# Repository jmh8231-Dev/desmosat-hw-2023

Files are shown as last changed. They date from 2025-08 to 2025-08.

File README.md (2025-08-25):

# DesmoSAT – 모듈형 캔위성 하드웨어 (2023)

> 모듈화를 통해 **저비용·고유연성**을 달성한 소형 위성 하드웨어 플랫폼  
> 공통 코어 + 교체식 임무 보드 + 착륙 보드 = 빠른 재사용/응용

<!-- 히어로: 실물 사진 준비 전, 회로도 콜라주로 임시 노출 -->
<!-- 실물 사진을 올리면 아래 경로로 교체: docs/images/hero-boards.png -->
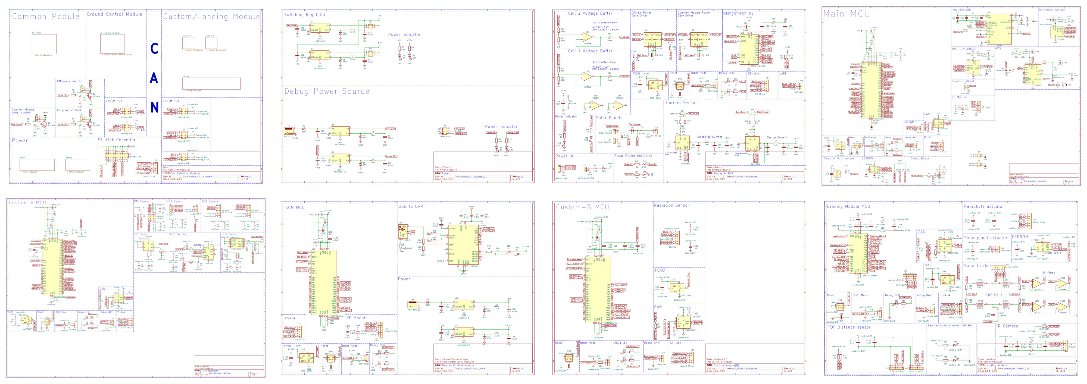
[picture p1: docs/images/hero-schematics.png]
DesmoSAT Boards


## 개요
DesmoSAT은 **모듈 교체만으로 임무를 바꿀 수 있게 설계된 캔위성(CanSat) 하드웨어 플랫폼**입니다.  
공통 코어(Common)와 전력/배터리 관리(BMS), 임무 모듈(Custom A/B), 착륙 모듈(Landing)을 단일 **CAN 2.0B** 버스로 연결하고, **전원·통신·ST-Link가 표준화된 인터페이스**로 제공되어 보드를 ‘플러그인’처럼 교체하면 즉시 재사용이 가능합니다.  
이 구조는 설계 변경 범위를 최소화해 **개발 기간을 단축**하고 **반복 제작 비용을 절감**하며, 현장 운용 중에도 유지보수와 확장을 쉽게 합니다.  
데모 임무로는 **화산 위험 징후 탐지**(가스/분진, IR/VL, ToF 기반)를 구현했습니다.

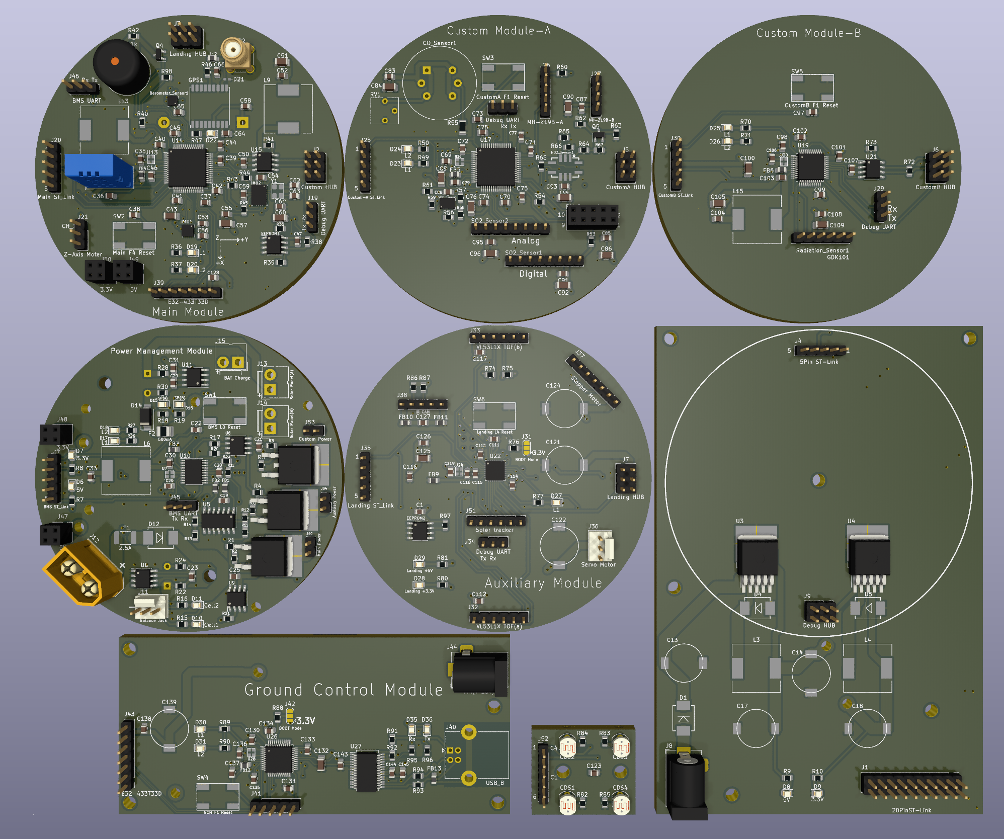
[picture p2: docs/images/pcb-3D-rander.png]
DesmoSAT PCB


## 핵심 포인트
- **모듈 스왑 기반 임무 전환**: 공통 코어는 유지, 임무 보드만 교체 → 빠른 재활용/확장  
- **표준화된 인터페이스**: 전원·CAN·ST-Link 핀아웃 통일 → 설계/디버그 일관성 확보  
- **개발/운용 효율**: 변경 영향 범위 축소 → 개발 기간 단축, 반복 제작·정비 비용 절감  
- **데모 임무**: 화산 위험 징후 탐지(가스/분진 + IR/VL + ToF), 군사 동향 정찰 위성(방사능 센서 + IR/VL + ToF)

> 설계/출력 도구: **KiCad 8/9** 

---

## 모듈 구조

| 모듈 | 목적(키워드) | 핵심 부품(키워드) |
|---|---|---|
| **Common** | 비행 컴퓨터/통신/센서 허브 | STM32F4, CAN(SN65HVD231), RF(433 MHz 1 W), GPS(MAX-M10S), IMU(BNO085/ICM-20602), Baro(LPS22HB), EEPROM |
| **Battery & BMS** | 전원/충전/안전 관리 | STM32L0, LM2596S 5 V/3.3 V, INA219B(전류), LM324A(셀버퍼), TC427(파워 게이팅), Solar 입력 |
| **Custom A** | 화산 임무용 가스/분진 센싱 | STM32F4, SO₂/CO/CO₂/CH₄/TVOC/PM 센서, CAN, TCXO |
| **Custom B** | 방사선 임무(확장) | STM32F1, GDK101(방사선), CAN, TCXO |
| **Landing** | 낙하/착지/추적 | STM32L4, VL53L1X(ToF), IR/VL 카메라 I/F, CDS 트래커, 서보/스테퍼, CAN |
| **Ground Control** | 지상국 수신/표시 | STM32F1, RF(E32-433T30D), FT232RL(USB-UART) |

<!-- 블록 다이어그램(상위 시트) 스크린샷 -->
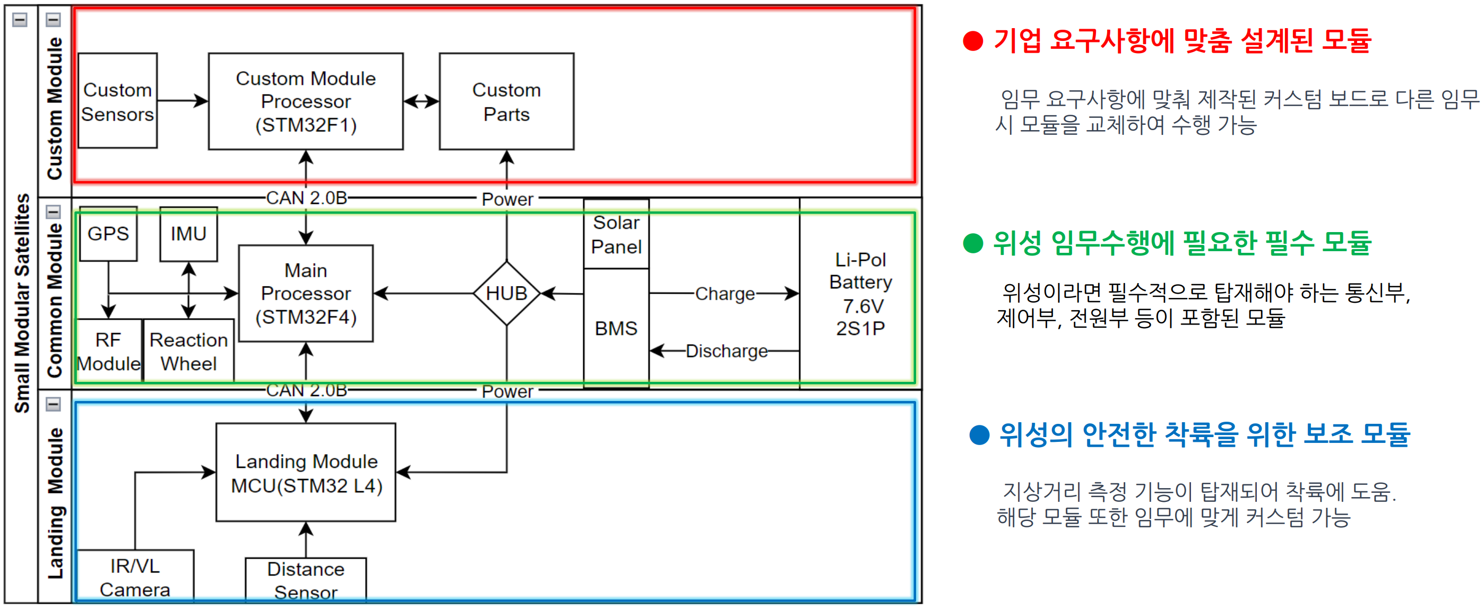
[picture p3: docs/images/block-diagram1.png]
Block Diagram

---

## 데모 임무 A: 화산 위험 징후 탐지
  활화산의 불안 징후를 감지하여 해당 화산의 폭발이 임박했는지 데이터를 지속
해서 Logging 하여 화산이 폭발하기 전 지역 주민이 대피할 수 있도록 하는 위성
이다.
  해당 캔 위성에는 화산에서 분출되는 다양한 가스의 농도를 측정해주는 모듈이
장착되어 화산 상공에서 낙하하며 각 가스의 농도를 측정한다. 그 후 착륙 모듈에
장착된 VL, IR 카메라를 사용하여 화산 상공의 모습과 화산지역의 온도를 측정한
다. 그 후 비교적 온도가 낮은 지역으로 낙하산 줄을 조정하여 착륙을 유도하고 착
륙한 뒤에는 메인 모듈에 내장된 IMU를 사용하여 화산지역의 지진파를 지속해서
측정한다.
  마지막으로 각 모듈에서 수집된 데이터를 기반으로 메인 컴퓨터가 화산 분화 가
능성을 대략 연산한 뒤 각 센서 수치와 함께 안전한 곳에 있는 지상국으로 데이터
를 보내주어 지질학자가 해당 데이터를 정밀 분석하여 해당 화산의 분화 가능성을
최종적으로 산출할 수 있다.

- **Custom A**: 하강 중 **SO₂/CO/CO₂/CH₄/TVOC/PM** 연속 측정 → 패킷 전송  
- **Landing**: **IR/VL 이미지**로 열점/지형 파악, **ToF**로 지면 거리 → **낙하산 라인 제어**(더 안전/저온 지역으로 착지 유도)  
- **Common**: 착지 후 **IMU 기반 미소진동(지진파) 모니터링**, RF 링크로 지상국에 로그 전송  
- **지상국**: 실시간 그래프/지도화, **베이스라인 대비 변화량** 분석

<!-- Custom A: 실물 사진 준비 전, 회로도 이미지 임시 노출 -->
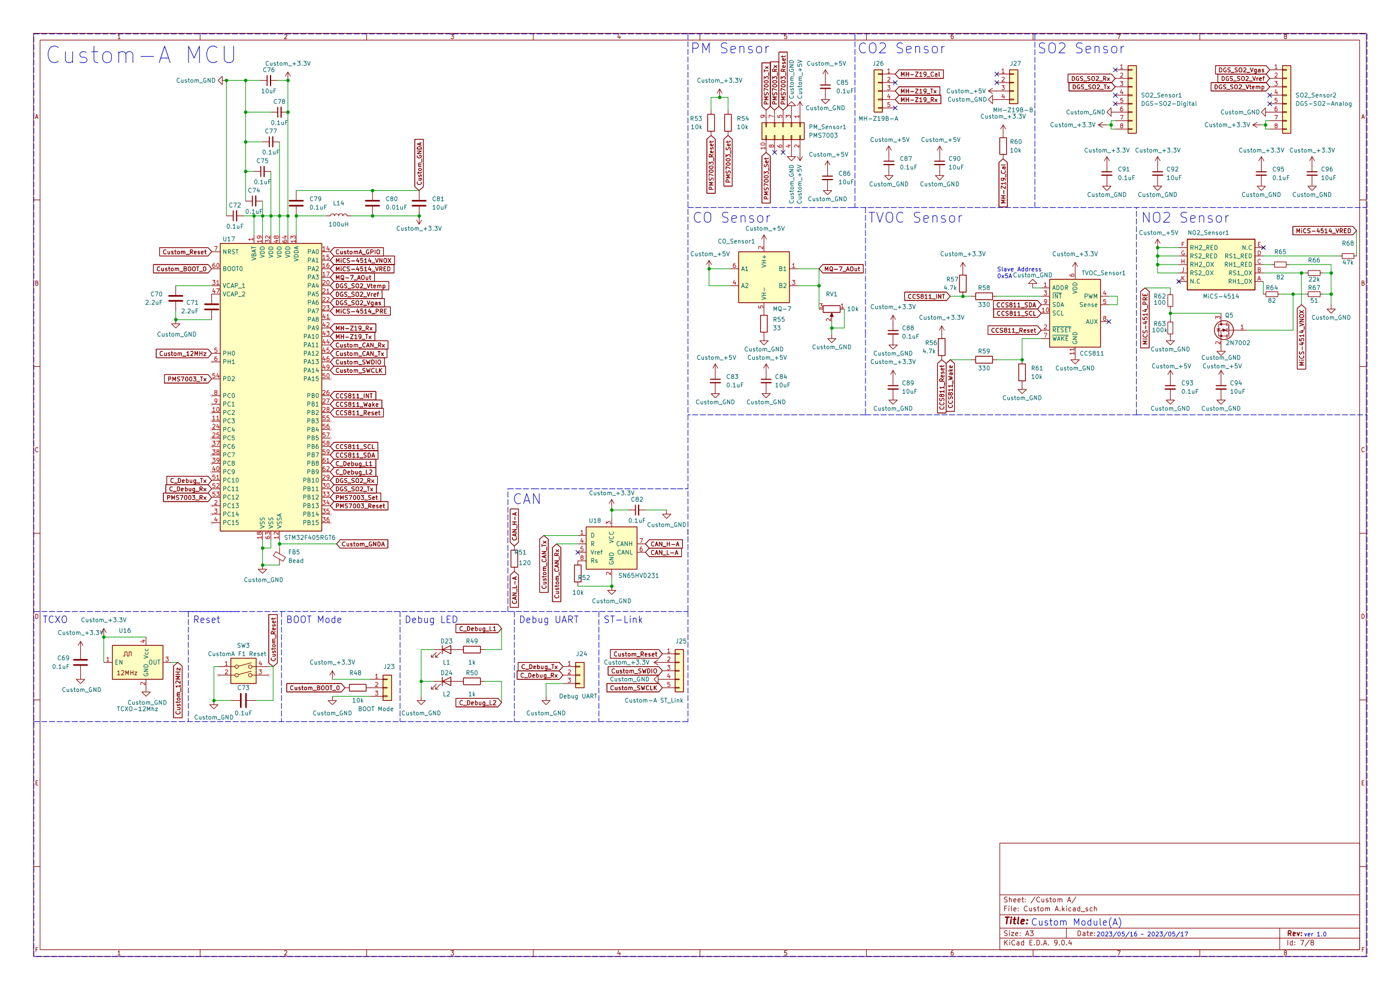
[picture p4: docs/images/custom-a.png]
Custom A – Gas/PM Payload


## 데모 임무 B: 군사 동향 정찰 위성
  적국의 핵실험 유무 및 국사적 움직임을 관측하기 위해 최상단 모듈을 방사능
측정 센서와 풍향 풍속 센서가 장착된 모듈로 교체한 뒤 캔 위성을 발사하여 핵실
험 유력 장소 상공 방사능 농도를 측정한다. 동시에 착륙 모듈에 장착된 IR/VL 카
메라를 사용하여 지표의 온도, 이미지를 보고 핵실험 유무를 판단할 수 있다.
  착륙한 뒤에는 화산 위험 징후 감지 위성과 동일하게 메인 모듈에 내장된 IMU
를 사용하여 지진파를 지속해서 감지하기 때문에 추가적인 핵실험 여부도 판단할
수 있는 위성이다. 
  또한 같은 위성을 원전 사고 현장에 발사한다면 방사성 물질의
피해 범위를 산출할 수도 있다

- **Custom B**: 하강 중 **방사능 농도** 연속 측정 → 패킷 전송  
- **Landing**: **IR/VL 이미지**로 열점/지형 파악, **ToF**로 지면 거리 → **낙하산 라인 제어**(목표 지역으로 유도 및 핵실험 유무 판단)  
- **Common**: 착지 후 **IMU 기반 미소진동(지진파) 모니터링**, RF 링크로 지상국에 로그 전송(추가 핵실험 판단)
- **지상국**: 실시간 그래프/지도화, **베이스라인 대비 변화량** 분석

<!-- Custom B: 실물 사진 준비 전, 회로도 이미지 임시 노출 -->
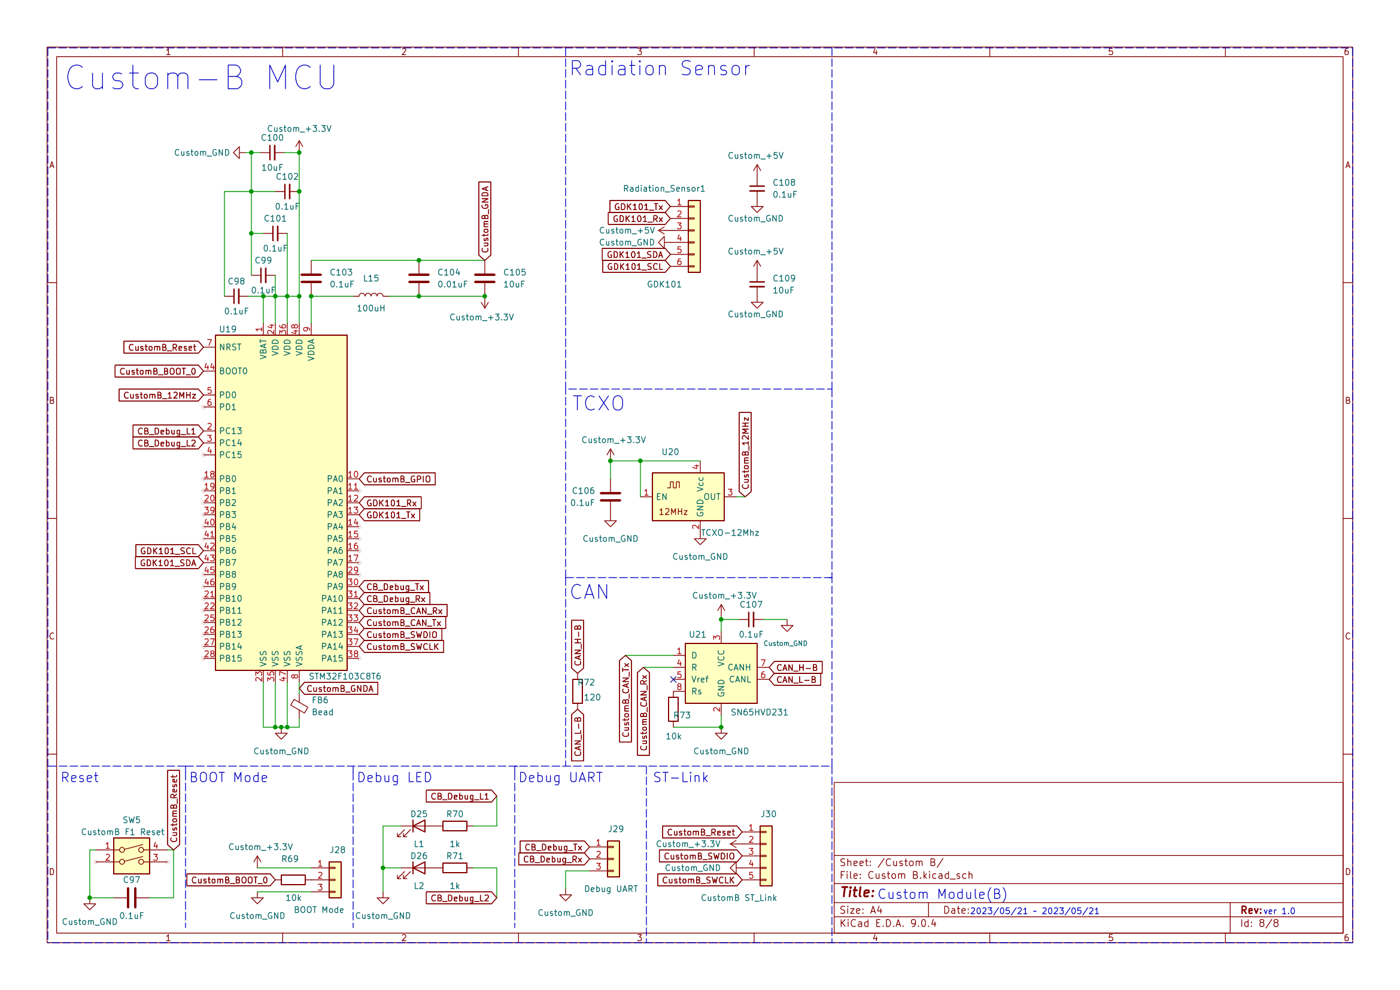
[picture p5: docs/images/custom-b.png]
Custom B – Gas/PM Payload


---

## 시스템 개요

### 통신/제어
- **CAN 2.0B**: 모듈 간 명령·텔레메트리 버스
- **RF 433 MHz 1 W**: 지상국 링크(센서/상태/좌표)
- **ST-Link**: 전 모듈 SWD 디버그/펌웨어 업데이트

### 전원/충전
- **Li-Po 2셀 + BMS**: 저전압 보호/전류 모니터/모듈 파워게이팅
- **스위칭 레귤레이터**: LM2596S-5/-3.3 (효율), 디버그 전원 레일 분리
- **Solar 충전**: 배터리 레벨에 따라 모듈 **절전/복귀** 제어

### 센서/액추에이터
- **가스/분진**: SO₂, CO, CO₂, CH₄, TVOC, PM
- **IMU**: BNO085(9축), ICM-20602(6축)
- **GPS**: MAX-M10S
- **CDS Solar Tracker**: 4-셀 + LM324A 버퍼
- **ToF**: VL53L1X
- **IR/VL 카메라**, **리액션 휠**, **스테퍼(낙하산)**, **서보(패널)**

---

## 파일/폴더 구조

```text
desmosat-hw-2023/
├─ common_module/        # 메인 MCU, CAN, 센서, RF
├─ battery_bms/          # 배터리/충전/BMS
├─ custom_module_a/      # 가스/분진 페이로드
├─ custom_module_b/      # 방사선 페이로드(옵션)
├─ landing_module/       # 낙하/착륙(서보/스테퍼/ToF/카메라)
├─ ground_control/       # 지상국 MCU + RF + USB
├─ docs/
|    ├─ images/          # README 이미지(.png)
|─ 임무제안서             # 위성 임무설명 문서
```
---

> **Firmware repo**: [https://github.com/ORG/REPO-FW  ](https://github.com/jmh8231-Dev/desmosat-fw-2023)

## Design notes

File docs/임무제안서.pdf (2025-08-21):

2023 캔위성 체험․경연대회 임무제안서

# 모듈화 설계된 캔위성을 사용한 고효율 위성

# 시스템

1. 참가동기

기존부터 항공우주기술에 관심이 있었으며, 관련 자료들을 찾기도 하였다. 위성 에 관련된 자료들을 서칭하는 과정에서 캔위성 체험․경연대회의 존재를 알게 되었 다. 이를 통해 경연대회의 수상작을 보게 되었고, 재밌는 아이디어들로 본인의 위성 을 제작하고 직접 확인해보는 것이 본 대회에서 얻을 수 있는 특별한 경험이라고 판단해 참가하게 되었다.
또한 위성(우주산업)은 국가, 기업, 기타 기관 등에서 지속적으로 관심이 높아지 고 있는 분야이며 요구사항도 점점 다양해지는 만큼 우주산업 시장은 계속해서 성 장하고 있다.

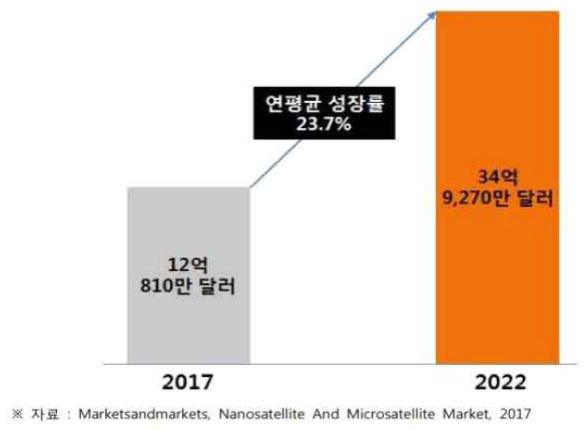
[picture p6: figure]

<그림 1>

하지만 비용적인 부담이 크기 때문에 실제로 활용이 쉽지 않은 것이 현실이다. 캔 위성 같은 나노 위성의 경우 비용적인 부담을 줄일 수 있다. 따라서 비용적인 부담을 최소화하여 소형 기업, 소형 기관에서도 쉽게 접근할 수 있는 위성을 제작 하는 프로젝트를 진행하여 위성을 상용화할 수 있는 발판을 만드는 것이 최종 목적 이다. 이를 통해
첫째. 위성 모듈화를 통한 비용 절감
둘째. 인공위성의 다양한 요구사항에 맞출 수 있는 유연한 플랜트
셋째. 개발 기간 문제 해결이 가능한 인공위성 시스템
넷째. 위성의 대중화 등의 효과 창출이 가능하다.

- 2 -
2. 팀 구성 및 역할

2.1 인원별 세부 개발 항목

정명훈

### - 위성 PCB Artwork - spec에 맞는 ARM Processor 선정 및 기술조사 - Common Module 구현(M7 사용) - Landing Module FW 개발(M4 사용) - Custom Module 센싱 및 제어부분 구현(M1 사용)

- 착륙 위치제어 알고리즘 개발
- 지상국 SW 개발
- 기술 조언

권오성

### - 3D Print modelling Tool을 이용한 전반적인 위성의 구조 최적화 설계

- 착륙 위치제어용 낙하산 설계
- SOLIDWORKS를 통한 낙하산 공기역학 해석

정지민
- 지상국 통신 프로토콜 개발
- 지상국 SW 개발
성명 | 소속 학과 | 역할 | 내용
정명훈 | 전자공학과 | 팀 리더 | - DesmoSAT PCB Artwork - DesmoSAT FW 개발
권오성 | 전자공학과 | 구조 설계 데이터 분석 | - 위성 구조 3D 설계
정지민 | 전자공학과 | SW 설계 | - 지상국 설계

- 3 -
3. 임무 목표
1957년 10월 4일 세계 최초의 인공위성인 [스푸트니크]가 발사된 지 68년이 지났

다. 그간 인류의 인공위성 기술은 매우 가파르게 발전하였고 국가, 기업, 기타 기관

의 인공위성 수요 또한 발맞춰 높아졌다. 하지만 기존 인공위성은 많은 고성능 센

서를 탑재한 대형위성 위주로 설계가 이루어져 비용이 매우 비싸 자본이 충분하지 않은 소형 기업, 소형 기관은 인공위성 사용에 큰 어려움을 겪고 있다. 또한 기업의

인공위성 요구사항도 점점 다양해지고 있어 인공위성 개발 기간이 오래 걸리는 문

제도 존재하기 때문에 인공위성을 모듈화해 공통된 모듈은 하나로 통합하여 사용하 는 모듈화 캔 위성을 사용하여 하기(3.1)에 작성한 임무를 수행한다. 하지만 대회에

서 발사는 1회만 진행되기 때문의 대회에서는 화산 위험징후 감지 위성만 시연한

다.

3.1. 화산 위험징후 감지 위성

활화산의 불안 징후를 감지하여 해당 화산의 폭발이 임박했는지 데이터를 지속 해서 Logging 하여 화산이 폭발하기 전 지역 주민이 대피할 수 있도록 하는 위성 이다.
해당 캔 위성에는 화산에서 분출되는 다양한 가스의 농도를 측정해주는 모듈이 장착되어 화산 상공에서 낙하하며 각 가스의 농도를 측정한다. 그 후 착륙 모듈에 장착된 VL, IR 카메라를 사용하여 화산 상공의 모습과 화산지역의 온도를 측정한 다. 그 후 비교적 온도가 낮은 지역으로 낙하산 줄을 조정하여 착륙을 유도하고 착 륙한 뒤에는 메인 모듈에 내장된 IMU를 사용하여 화산지역의 지진파를 지속해서 측정한다.
마지막으로 각 모듈에서 수집된 데이터를 기반으로 메인 컴퓨터가 화산 분화 가 능성을 대략 연산한 뒤 각 센서 수치와 함께 안전한 곳에 있는 지상국으로 데이터 를 보내주어 지질학자가 해당 데이터를 정밀 분석하여 해당 화산의 분화 가능성을 최종적으로 산출할 수 있다.
3.2. 군사 동향 정찰 위성

적국의 핵실험 유무 및 국사적 움직임을 관측하기 위해 최상단 모듈을 방사능 측정 센서와 풍향 풍속 센서가 장착된 모듈로 교체한 뒤 캔 위성을 발사하여 핵실 험 유력 장소 상공 방사능 농도를 측정한다. 동시에 착륙 모듈에 장착된 IR/VL 카 메라를 사용하여 지표의 온도, 이미지를 보고 핵실험 유무를 판단할 수 있다. 착륙한 뒤에는 화산 위험 징후 감지 위성과 동일하게 메인 모듈에 내장된 IMU 를 사용하여 지진파를 지속해서 감지하기 때문에 추가적인 핵실험 여부도 판단할 수 있는 위성이다. 또한 같은 위성을 원전 사고 현장에 발사한다면 방사성 물질의 피해 범위를 산출할 수도 있다

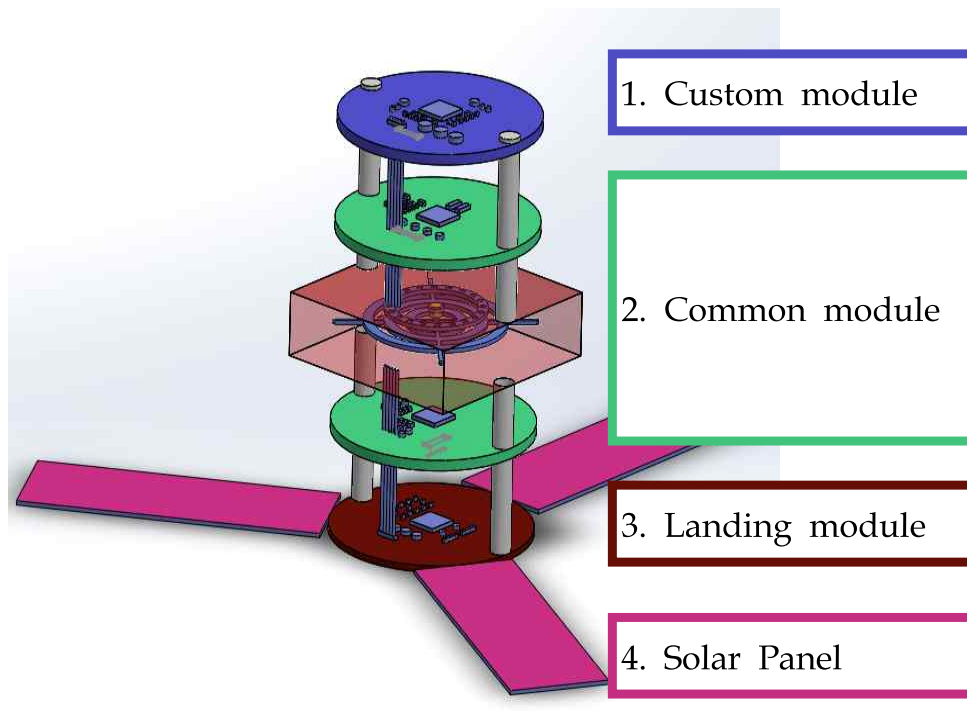
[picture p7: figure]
1. Custom module; 2. Common module; 3. Landing module; 4. Solar Panel

- 4 -
4. 개념설계 및 개발방안

4.1.1 Cansat 구조(초안)
Can 위성을 3개 모듈로 나누어 각각 Custom Module, Common Module, Landing Module로 나누어 설계한다.

<그림 4-1>

### 1. Custom module

임무요구사항에 맞게 설정된 커스텀 보드이며, 각종 센서들이 탑재돼 탈부착

형식으로 만약 다른 임무가 필요하다면 Custom module을 교체해 유연한 임무

수행이 가능하다.

### 2. Common module

위성 임무수행에 필요한 공통적인 요소가 들어있으며, 통신부, 제어부, 전원부

등이 포함

### 2. Reaction Wheel

Common module에 포함되며 관성모먼트를 사용하여 위성의 Z축(Yaw) 자세

제어를 하는 부분(태양전지판 효율을 높이기 위해 사용된다.)

### 3. Landing module

위성이 공중에서 임무 수행을 마친 뒤 지상에 착륙하기 직전 지상과의 거리값

을 받아오며 안전한 착륙이 가능하게 도움을 주는 모듈

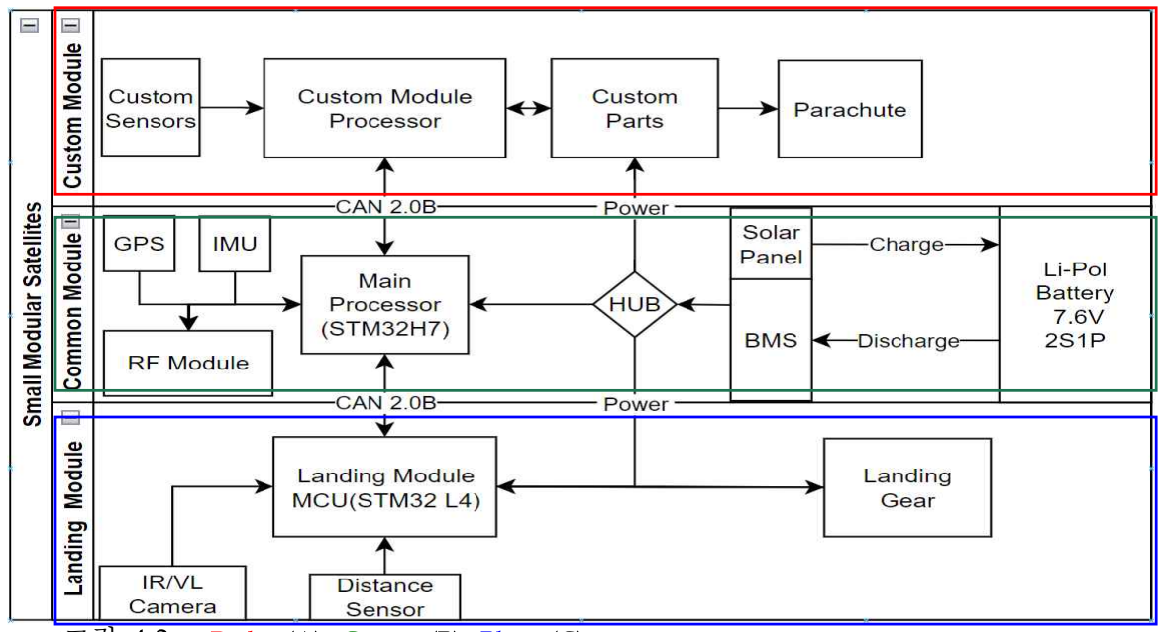
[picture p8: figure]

- 5 -

4.1.2 Cansat Block Diagram

<그림 4-2> Red : (A), Green: (B), Blue :(C)

Block diagram description:

### 1. 위성은 (A): Custom Module, (B): Common Module, (C): Landing Module로 3

개로 모듈화 되어 나뉜다.

2. 모든 임무는 그림의 가운데 위치한 (B) 모듈을 사용하며 용도에 맞게 A를 커스

텀 하여 사용한다.
3. 각 (A), (B), (C) 모듈 사이에 통신은 CAN 2.0B를 사용하여 통신한다.
4. 전원은 (B) 모듈 내부에 배터리를 내장하고 있으며 태양전지판을 사용하여 충전
한 뒤 BMS와 Power HUB를 통해 (A), (C) 모듈로 나눠진다.
5. Li-Pol 배터리 특성상 특정 전압 이하로 방전이 되면 배터리 수명이 급격하게 떨

어지기 때문에 배터리 관리 모듈인 BMS를 사용하여 배터리 전압이 일정 수준

이하로 떨어지는 걸 방지한다.

6. 태양전지판에서 생산된 전력으로 내부 배터리를 충전하며 만약 내부 배터리 레

벨이 낮다면 BMS가 HUB를 통해 각 모듈로 가는 전력을 제어하여 절전모드로

빠진 뒤 배터리 레벨이 일정 이상으로 회복되면 다시 정상 가동을 시작한다.

7. (A), (C) 모듈에서 들어온 여러 데이터를 (B) 모듈이 해석, 연산하여 작업을 수행

한다.

8. 지상국과의 통신은 (B) 모듈에 내장된 RF 모듈(433MHz 1W)을 사용하여 통신한

다.

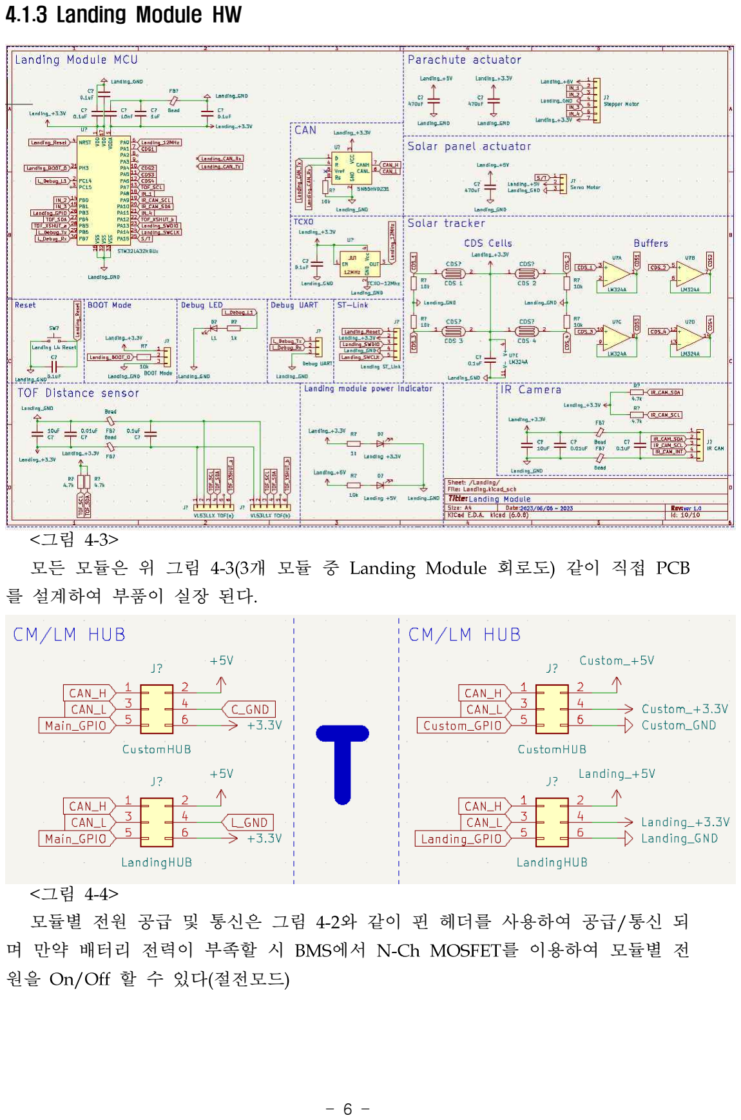
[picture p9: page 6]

- 6 -

4.1.3 Landing Module HW

<그림 4-3>

### 모든 모듈은 위 그림 4-3(3개 모듈 중 Landing Module 회로도) 같이 직접 PCB

를 설계하여 부품이 실장 된다.

<그림 4-4>
모듈별 전원 공급 및 통신은 그림 4-2와 같이 핀 헤더를 사용하여 공급/통신 되 며 만약 배터리 전력이 부족할 시 BMS에서 N-Ch MOSFET를 이용하여 모듈별 전 원을 On/Off 할 수 있다(절전모드)

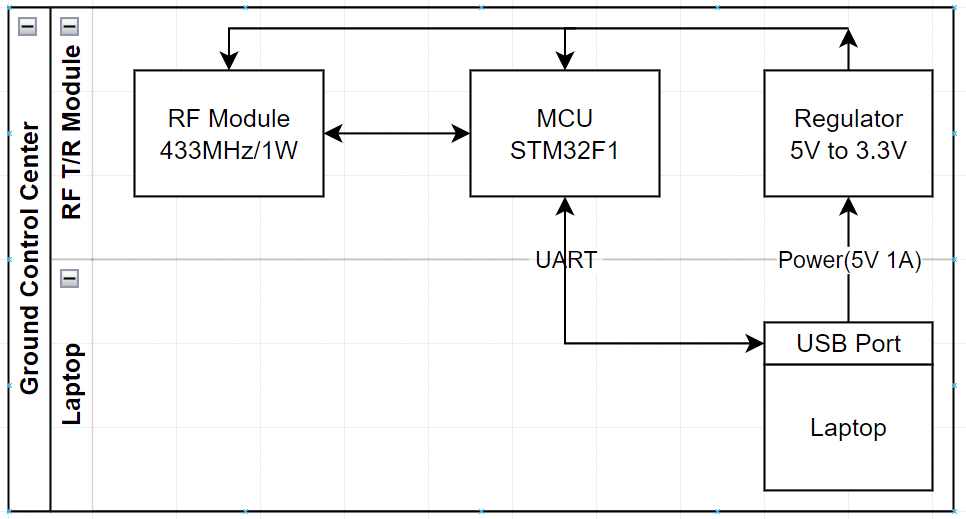
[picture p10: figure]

- 7 -

4.2.1 지상국 Block Diagram

<그림 4-5>

Block diagram description:

1. 지상국은 RF Module을 사용하여 데이터를 수신한다.

### 2. 수신받은 데이터는 MCU를 통해 Parsing/Processing 되어 UART를 통해 Laptop

으로 전달된다.

3. 가공된 데이터를 전달받은 Laptop에서 GUI를 사용하여 데이터를 가시적으로 보

여준다.

4. Laptop의 USB Port를 통해 전원을 공급받으며 내부 레귤레이터를 통해 3.3V로

강압된 후 내부 모듈에 분배된다.

4.2.2 지상국 기능

MCU를 통해 처리된 데이터를 UART로 수신하여 수신된 값을 GUI를 통해 그래 프로 보여줘 해당 값을 지질학자가 전문 분석하여 화산의 위험징후를 최종적으로 판단하는데 도움을 준다. 또한 위성의 위치, HW 상태 등 여러 가지 항목이 모니터 링 되기 때문에 위성의 수명을 예측할 수 있다.

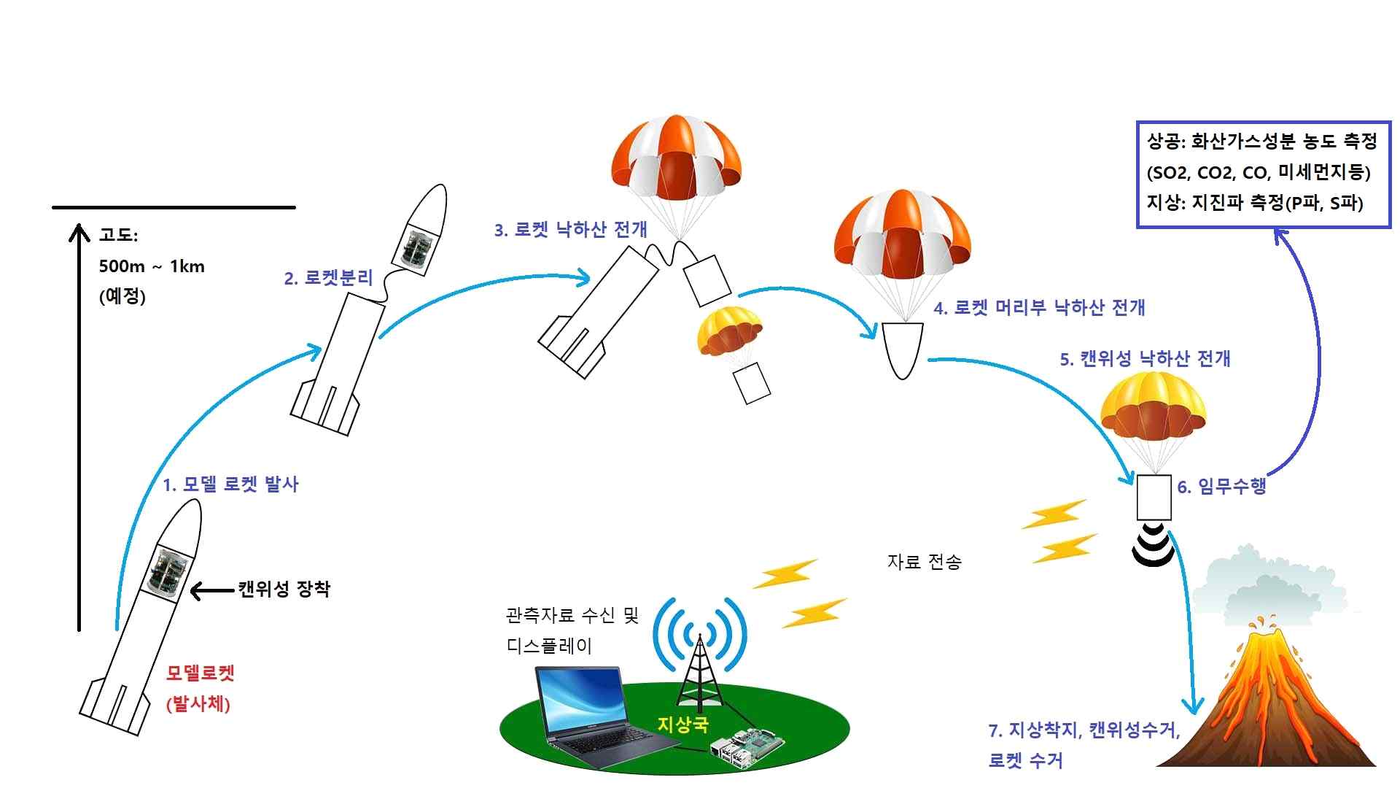
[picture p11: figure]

- 8 -
5. 관측데이터 활용방법

### Common Module에는 온도, 습도, 위성 자세(IMU), 위성 위치(GPS), 태양의 위

치를 파악할 수 있는 센서(CDS)와 함께 태양을 추적하기 위해 위성의 동체를 회전
시키는 리액션 휠(Reaction wheel)이 부착된다.
먼저 대기 중의 온도와 습도를 파악하여 지상국에 데이터를 송신하여 지상국에 서는 해당 지역의 현재 온도와 습도를 파악할 수 있다. 위성 자체 내에서 현재 위 성의 자세 데이터를 수집하고 태양의 위치를 CDS 셀로 파악한다. 파악된 태양의 위치로 위성이 바라보는 면을 리액션 휠(Reaction wheel)을 사용하여 위성의 자세와 각도를 조절한다.
위성의 IMU 센서를 이용하여 평시의 위성 X, Y, Z를 저장하고 지속해서 감지하 며 대지의 떨림, 흔들림을 X, Y, Z축의 변화로 감지하여 화산지역의 지진파를 감지 한다. 그리고 위성의 위치를 GPS로 지상국과 통신하고 착륙 후에 목표지역 내 어디 에서 임무를 수행하는지 지상국은 파악할 수 있다.

<그림 5-1>
Custom Module A의 경우 화산지역에서의 임무 수행을 목표로 하고 있으므로 SO2 센서, 일산화탄소 농도 센서, 이산화탄소 농도 센서, 메탄알 농도 센서, 미세먼 지 농도 센서, 유기화합물 농도 센서가 부착된다. 평상시 휴화산의 데이터를 감지하 여 평시 데이터를 지상국에 저장한다.
일정 데이터를 수집했다면 위성을 수거하고 이후에 화산의 활동이 의심될 때, 혹 은 일정 주기로 측정이 필요한 경우 다시 위성을 발사하여 모듈에 부착되는 각각의 센서에 해당하는 기체 혹은 먼지의 데이터를 감지하여 지상국에 데이터를 전송하고 지상국에서 이전에 수집된 평시의 데이터와 비교하여 현재 휴화산의 활동량 변화와

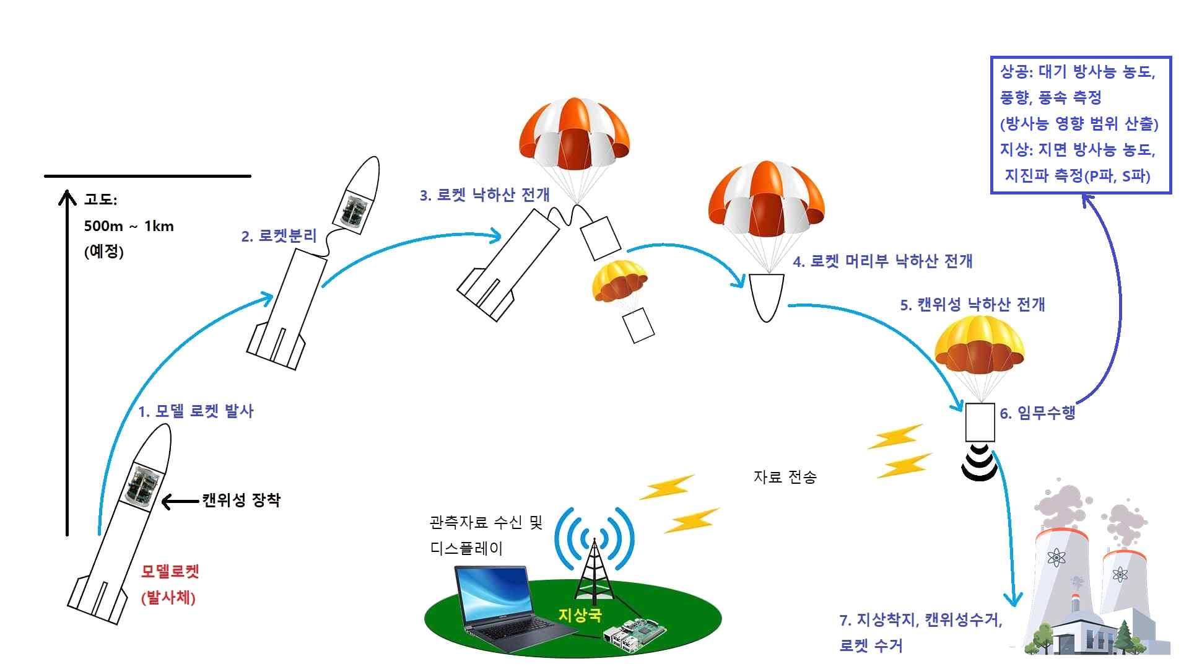
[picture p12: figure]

- 9 -

활동 가능성을 파악할 수 있다. 또 Landing Module에 탑재된 IR 이미지를 이용하 여 위성이 낙하함과 동시에 화산지역의 분화구와 그 주변의 대지의 지열 이미지를 파악할 수 있다.

<그림 5-2>

### Custom Module B의 경우 정찰위성으로 동작하기 때문에 Landing Module에 탑

재되는 IR 이미지를 도출하는 카메라를 통해서 사람의 움직임이나 공장 가동 시에 발생하는 열을 적외선으로 감지하여 사용자에게 데이터를 전송하고, VL 이미지를 촬영하는 카메라를 사용하여 높은 고도에서 정찰하고자 하는 지역을 탐색할 수 있 다. 또 방사능 농도 센서를 사용하여 현재 정찰하고 하는 지역에서 방사능이 발생 하는가, 혹은 핵을 사용한 실험 및 활동을 진행하고 있는지 위성의 정찰을 통해서 전송받은 데이터를 이용하여 지상국에서 비교 분석하여 결론을 도출할 수 있다.

### Landing Module의 경우 Commom Module과 같이 다목적 위성에 공통으로 들

어가는 부분이다. IR 이미지와 VL이미지 카메라가 탑재되고 현재 위성과 대지의 거 리를 파악하기 위한 적외선 센서가 부착된다. 위성이 착지하게 될 대지의 상태를 지상국에 전송하고 착지할 때 위성의 안정적인 착지를 위해서 적외선 센서를 이용 한다.

- 10 -
6. 일정 및 비용 추산
6.1. 캔위성 제작일정
No. | 수 행 내 용 | 개발일정(월)
5 | 6 | 7 | 8

### 1 Small Modular Cansat 아이디어 제안

### 2 Small Modular Cansat 세부 내용 기획

### 3 Small Modular Cansat 개발 방향 확립

### 4 Small Modular Cansat 공통 모듈(B) 개발 시작

### 5 Small Modular Cansat 공통 모듈(B) Test Case 작성 시작

### 6 Small Modular Cansat 공통 모듈(B)제작 완료

### 7 Small Modular Cansat 공통 모듈(B) Test Case 작성 완료

8 제작 완료된 Module(B) T/Cs 수행(Quality Assurance | 진행)

### 9 공통 모듈(B) T/Cs 결과 분석(모두 Pass 면 No. 11 실행)

### 10 공통 모듈(B) Failed 항목 Debug 진행

### 11 화산 위험징후 탐지용 Custom Module 개발 시작

12 화산 위험징후 탐지용 Custom Module Test Case 작성 | 시작

### 13 화산 위험징후 탐지용 Custom Module 제작 완료

14 화산 위험징후 탐지용 Custom Module Test Case 작성 | 완료
15 제작 완료된 Custom Module T/Cs 수행(Quality | Assurance 진행)
16 Custom Module T/Cs 결과 분석(모두 Pass 면 No. 18 | 진행)

### 17 Custom Module Failed 항목 Debug 진행

### 18 Small Modular Cansat 모델 제작 완료

### 19 Small Modular Cansat 모델 Full T/Cs 진행

### 20 Small Modular Cansat 모델 Failed 항목 Debug 진행

### 21 Cansat 경연대회 경연 및 Project 마무리

- 11 -
6.2. 위성 제작비 세부 내용(예상)
번호 | 품명 | 용도 | 수량 | 단 가(원) | 금 액(원)
1 | PCB(인쇄회로기판) Main Borad (4Layer) | | 3 | 50,000 150,000
2 | BNO085 | IMU/P파 S파 감지 | 1 | 26,854 | 26,854
3 | NEO-M9N-00B | GPS | 1 | 39,133 | 39,133
4 | MH-Z19B | CO2 Sensor | 1 | 42,500 | 42,500
5 | DHT22 | Temp/Hum/수증기 Sensor 1 | | 8,800 | 8,800
6 | DGS-SO2 | 아황산가스 Sensor | 1 | 67,000 | 67,000
7 | BME280 | 기압 Sensor | 1 | 37,500 | 37,500
8 | MLX90640 | IR Camera | 1 | 120,000 120,000
9 | GDK101 | Gamma Sensor | 1 | 50,000 | 50,000
10 | STM32H7 | Common Module MCU | 1 | 27,463 | 27,463
11 | STM32L4 | Landing Module MCU | 1 | 10,500 | 10,500
12 | STM32F1 | Custom Module MCU/지상국 | 2 | 2,400 | 4,800
13 | 필라멘트 | 3D Printer 재료 | - | 0(학교 무상 제공) | 0
14 | M3 서포트 등 | 구조물 지지대 | - | 50,000 | 50,000
15 | 배터리, 전지판 등 | 전력부 | - | 50,000 | 50,000
16 | 낙하산 | 낙하속도 감속 | 1 | 15,000 | 15,000
17 | 기타 부속품 | 기타 수동, 능동 소자 | - | 70,000 | 70,000
18 | 자세제어 엑츄에이터 | 위성 Z축 제어 | 1 | 30,000 | 30,000
합계: | | | | | 799,550원

- 12 -
7. 프로젝트 관리
7.1. 일정 관리 위험도 관리계획
수 행 내 용 | 추진일정 | 기 간
| 6 | 7 | 8 | (주) 5
위성 아이디어 확정 | | | | | 5/8~5/14
파츠 별 구현 방법 서칭 | | | | | 5/8~5/14
위성 아이디어 구체화 | | | | | 5/15~5/21
위성 개발 방향 확립 | | | | | 5/22~5/28
기능 선별 후 최적화 | | | | | 5/29~6/4
구체화된 아이디어 구현방법 서칭구현 | | | | | 5/29~6/4
구체화된 아이디어 구현 시작 | | | | | 6/5~6/11
각 모듈별 기능 시험 | | | | | 6/12~6/18
각 모듈별 기능 시험 | | | | | 6/19~6/25
각 모듈별 기능 시험 | | | | | 6/26~7/2
위성 프로토타입 제작 완료 | | | | | 7/3~7/9
1차 QA | | | | | 7/10~7/16
1차 기능 시험 및 디버깅 | | | | | 7/10~7/16
2차 QA | | | | | 7/17~7/23
2차 기능 시험 및 디버깅 | | | | | 7/17~7/23
최종 위성 제작 완료 | | | | | 7/24~7/30
예비기간 | | | | | 7/31~8/6
발표 | | | | | 8/7~8/13

- 13 -
7.2. 일정 관리 위험도 관리계획(세부)

연구실을 적극 활용, 주말 제외 매일 오후 18:00~22:00 공동 작업시간으로 정하 여 작업하며, 해당 주차에 맞는 수행내용을 공유, 수정 및 개선사항 조율하기 위해 매주 목요일에는 weekly를 진행한다. 또한 빠르게 위성 프로토타입 제작을 끝마쳐 일정 후반부에는 디버깅 및 QA를 통해 성능 개선 및 시스템 안정화에 힘쓴다.

- 개발환경 관리계획
학교 내 소속되어 있는 연구실을 공통 작업공간으로 사용하여 작업하며, Weekly 와 같은 회의는 학교 연구실과 학교 내 비어있는 강의실에서 진행한다. 제작 도구 및 장비 등은 연구실 내 갖춰져 있는 것을 적극적으로 활용한다. 개인이 소지한 개 인부품(센서 모듈)등도 필요시 프로토타입을 완성하기 이전 테스트 단계에 사용한 다.
- 기술적 위험도 관리계획
센서의 경우 서적을 참고하거나 오픈소스를 통해 동작 시연을 먼저 진행하고, 그 후 사용하는 MCU에 맞게 porting 하여 사용할 계획이다. 통신 및 제어 기술 등의 경우 다양한 강의 영상을 통하여 학습할 계획이다. 프로토타입이 제작되면 지속적 인 디버깅과 QA를 통해 오차 및 문제들을 해결한다.
- 비용 위험도 관리계획
비용 위험도 관리를 위해 제작 도구와 기타 수동/능동 소자, 필라멘트, 서포트 같은 부품의 경우 연구실에 갖춰져 있는 것으로 사용한다. 더해 연구실 지원금으로 일부 해결하며 추가로 구매가 필요한 도구와 장비 등은 추후 선발되었을 시 창작 임무 구현비를 통하여 사용한다.

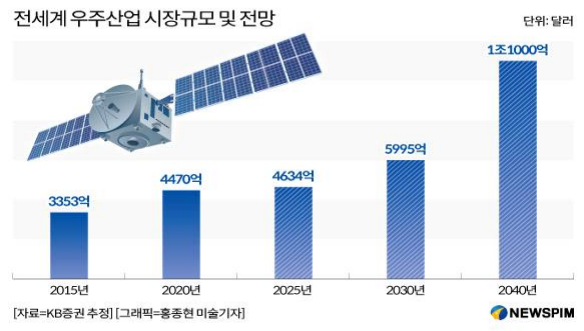
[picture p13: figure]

- 14 -
8. 성과물 홍보방법

우리의 Cansat은 HW 단에서 모듈화 설계되어 있으므로 발사하면 할수록 비용 이 절감된다는 장점이 있다.
예를 들어 사람의 접근이 제한되는 화산지역의 위험징후를 탐지해야 할 때 우리 Cansat을 발사한다면 인명피해 없이 화산 위험징후를 자유롭게 탐지할 수 있으며, 만약 위험하지 않은 지역으로 판단 될 때 위성을 다시 회수하여 다른 화산 위험징 후 탐지에 그대로 사용할 수도 있고 Custom Module만 교체해 준다면 전혀 다른 임무에 투입될 수 있다.
결과적으로 위성의 필요 용도가 달라짐에 따라 다른 위성을 개발하거나 구입할 필요 없이 Custom Module에 필요로 하는 데이터 관련 센서 혹은 모듈을 교체하여 부착해 주기만 한다면 해당 위성 하나만으로 다목적 운용이 가능하다. 즉 위성 개 발 비용이 기존에 비해 아주 큰 폭으로 절감할 수 있다.

<그림 9-1>

따라서 앞으로 우주 관련 시장이 급격하게 성장한다고 예측되는 현재 모듈화 위성 을 공장에서 자동차를 생산하듯 대량 생산하고 Space-X의 재활용 로켓과 같은 기술 과 융합된다면 위성 발사 비용이 기존에 비해 현저하게 저렴해질 것이라 예상되며 이로써 우리 Cansat은 비용 효율적인 해결책으로 많은 기업과 기관에 매력적인 선 택이 될 것입니다.
이러한 장점을 유튜브, 인스타그램과 같은 SNS를 통해 대대적으로 홍보한다면 앞으로 대한민국은 우주 강국이 되며 지금까지 존재한 적이 없던 위성과 로켓을 대 량 생산하는 대기업을 보유한 세계 유일의 나라가 될 수 있을 것이다.

- 15 -
9. 의견 기술
1. 위성을 설계하는데 지원되는 지원금이 더욱 높아져 수준이 높은 위성을 설계 할 수 있으면 좋을 것 같습니다.
2. 더욱 강력한 로켓을 사용하여 더 높은 고도에서 전개되어 다양한 임무가 수행 가능하면 좋겠습니다.
3. 참가인원을 5명으로 늘려 더욱 전문화된 개발을 할 수 있는 환경이 만들어진 다면 좋을 것 같습니다.
10. 참고문헌

모듈화 소형위성의 Data Bus 표준화 방안 연구 (https://www.dbpia.co.kr/pdf/pdfView.do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)

CPU 없는 자가 동력 태양광 트랙커 시스템 (https://www.dbpia.co.kr/pdf/pdfView.do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)

캔위성 대회를 위한 HW/SW 설계 및 구현 (https://satrec.kaist.ac.kr/) – KAIST 인공위성연구센터

PCB 설계기술 – 정성인

### STM32F103 정복 – 윤덕용

CanSat 나만의 인공위성 프로젝트 - 대학우주공학컨소시엄

나노 위성 및 마이크로 위성 시장 (https://www.innopolis.or.kr/fileDownload?titleId=176821&fileId=1&fileDownType=C&paramMenuId=MENU00999) - 연구개발특구진흥재단

지진을 이용한 화산감시 (https://koreascience.kr/article/JAKO201307954514395.pdf) – 강원대학교 지구물리학과 Landsat 열영상을 이용한 백두산 화산 분화 예지에 관한 연구 (https://www.dbpia.co.kr/pdf/pdfView.do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)

대기오염물질 정의 (https://www.air.go.kr/contents/view.do?contentsId=10&menuId=42) - 대한민국 환경부

모두의 아두이노 환경 센서 - 로니킴

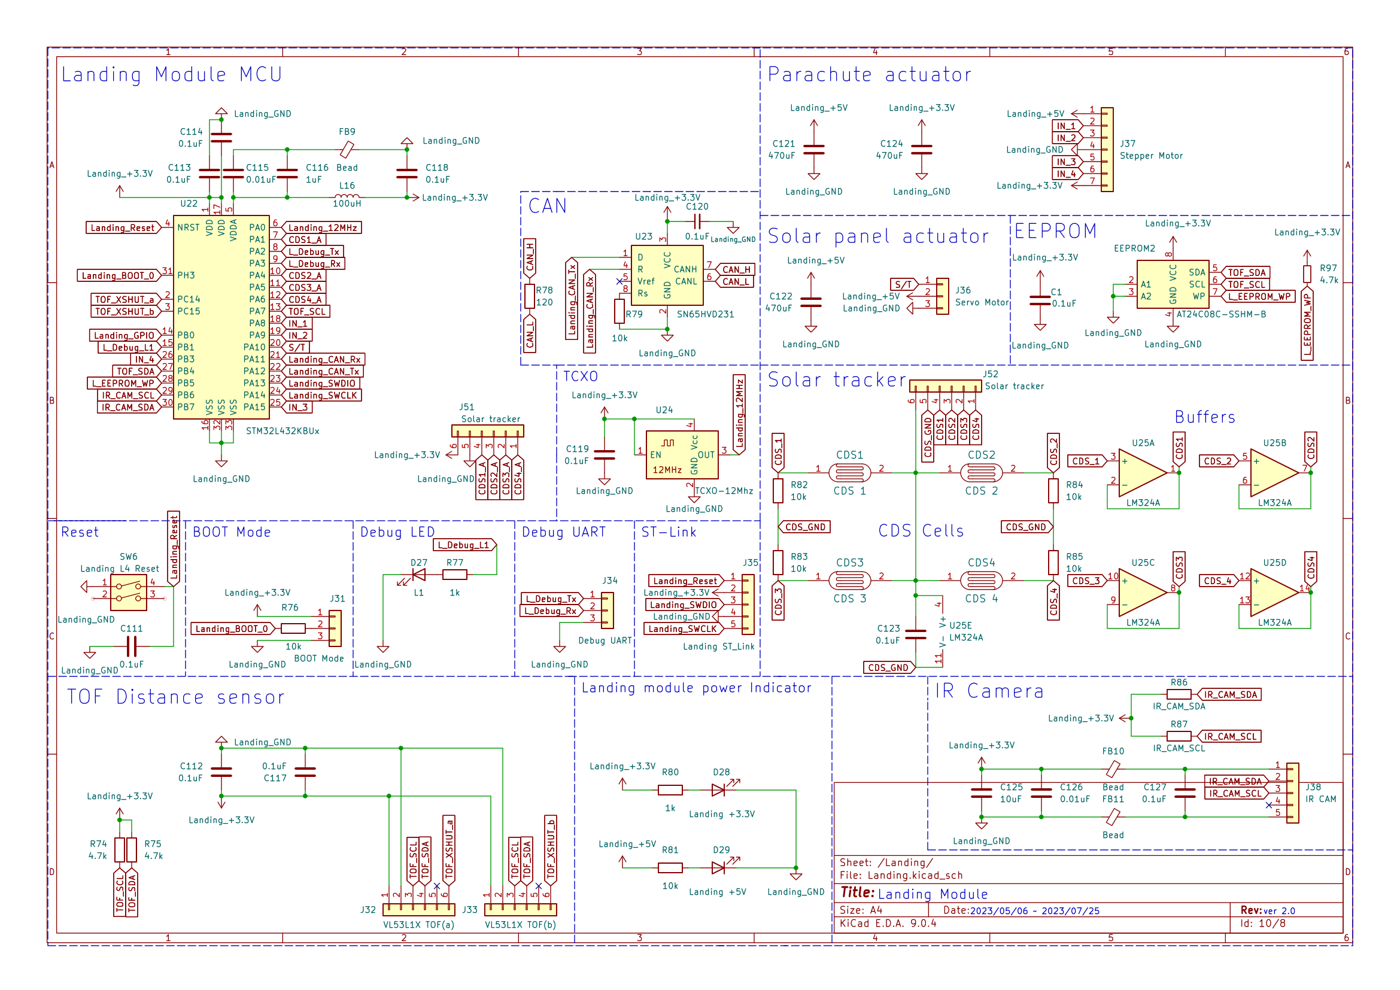
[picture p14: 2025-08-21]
docs/images/landing.png

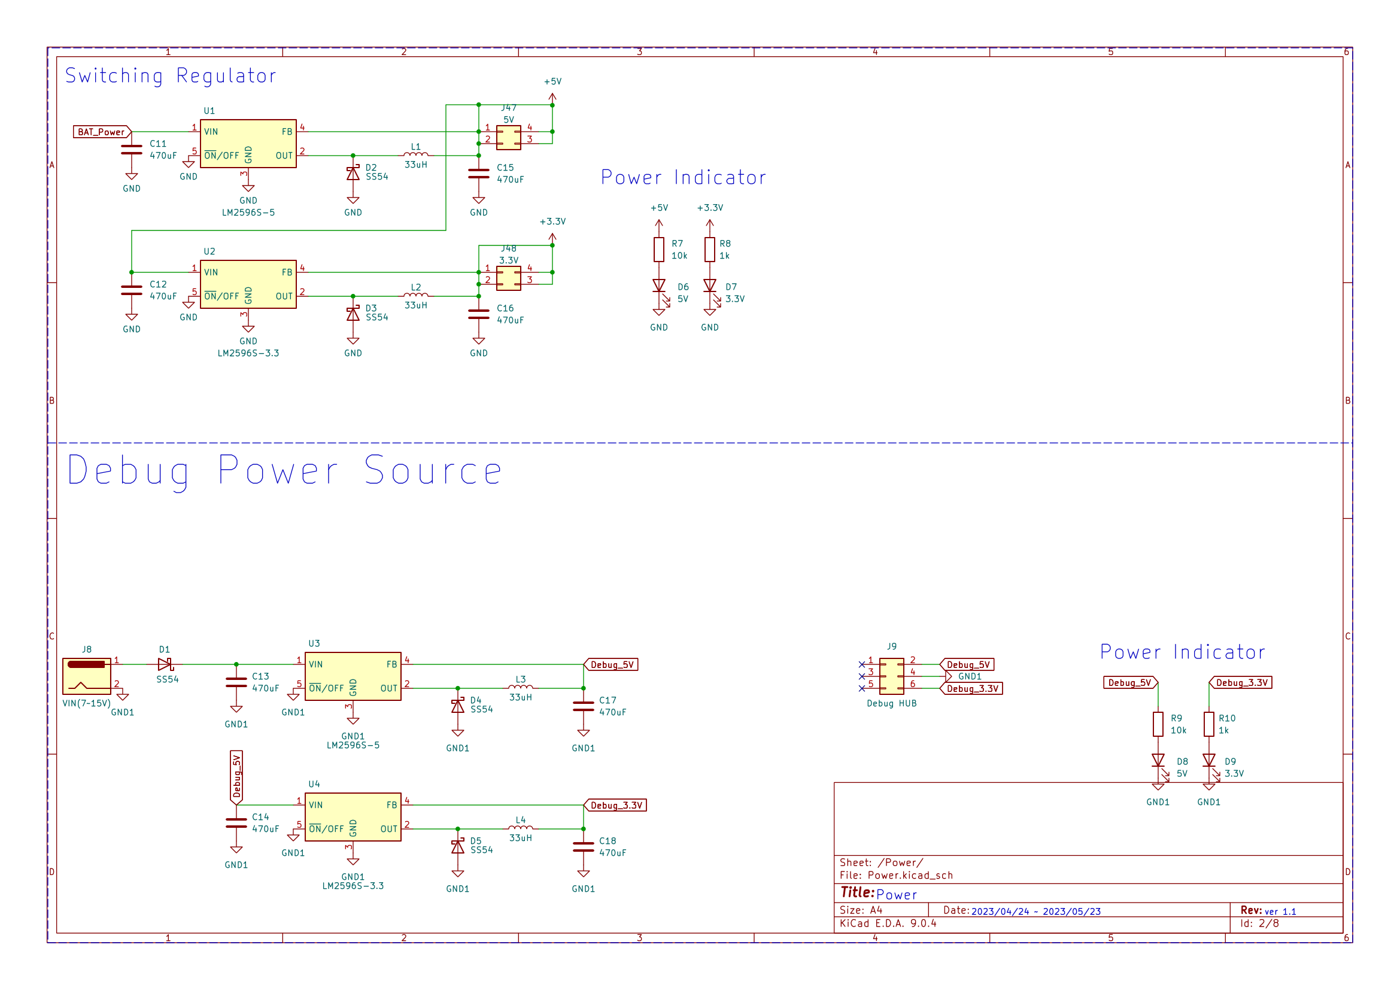
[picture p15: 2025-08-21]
docs/images/power.png

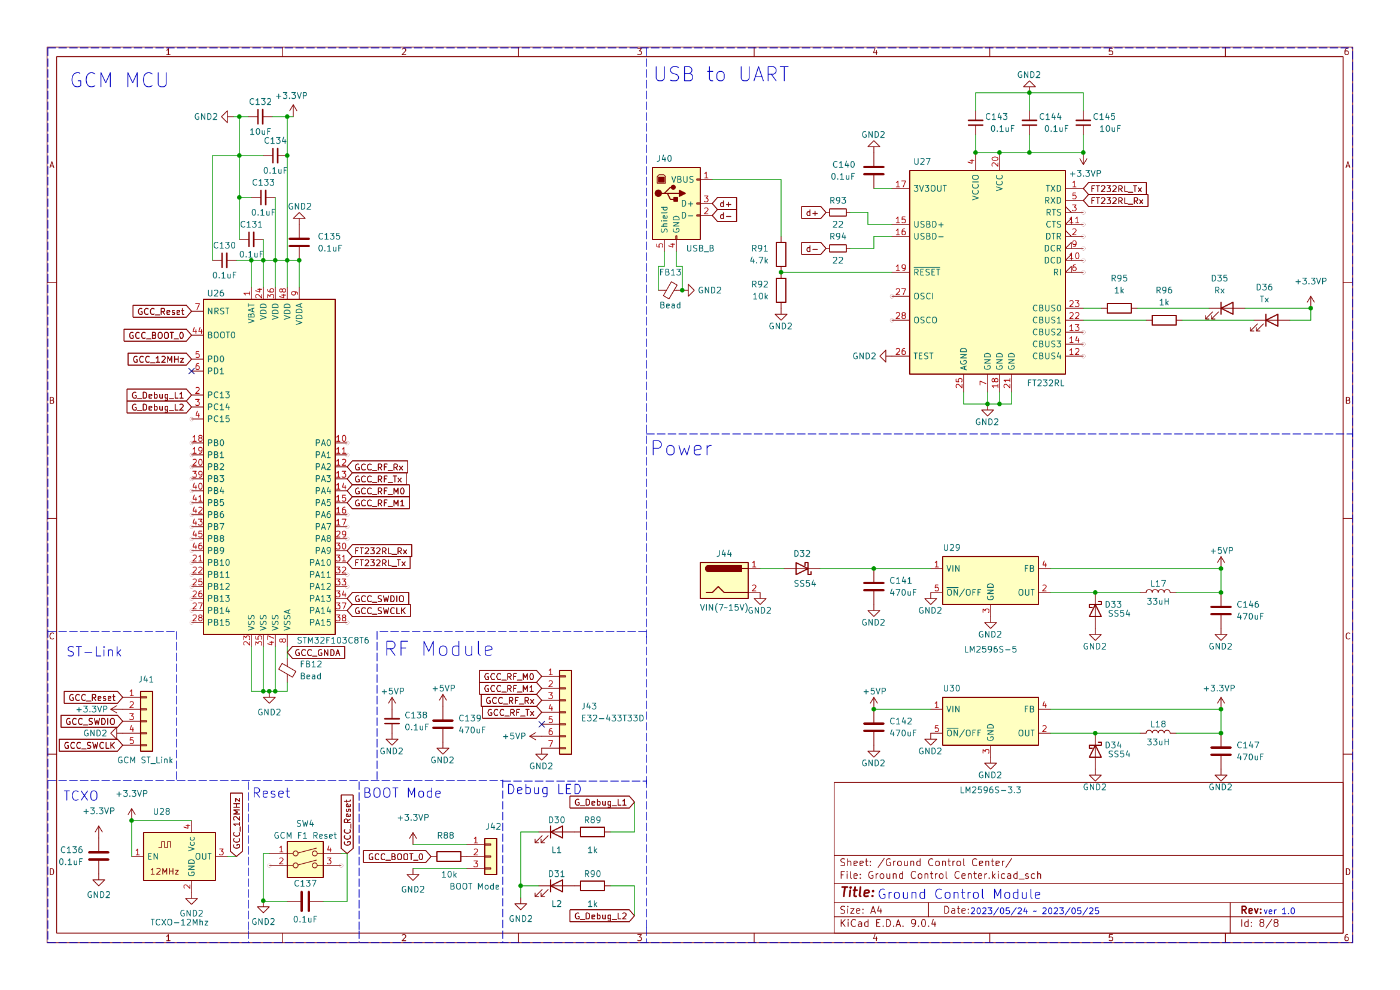
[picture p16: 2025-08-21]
docs/images/ground-control.png

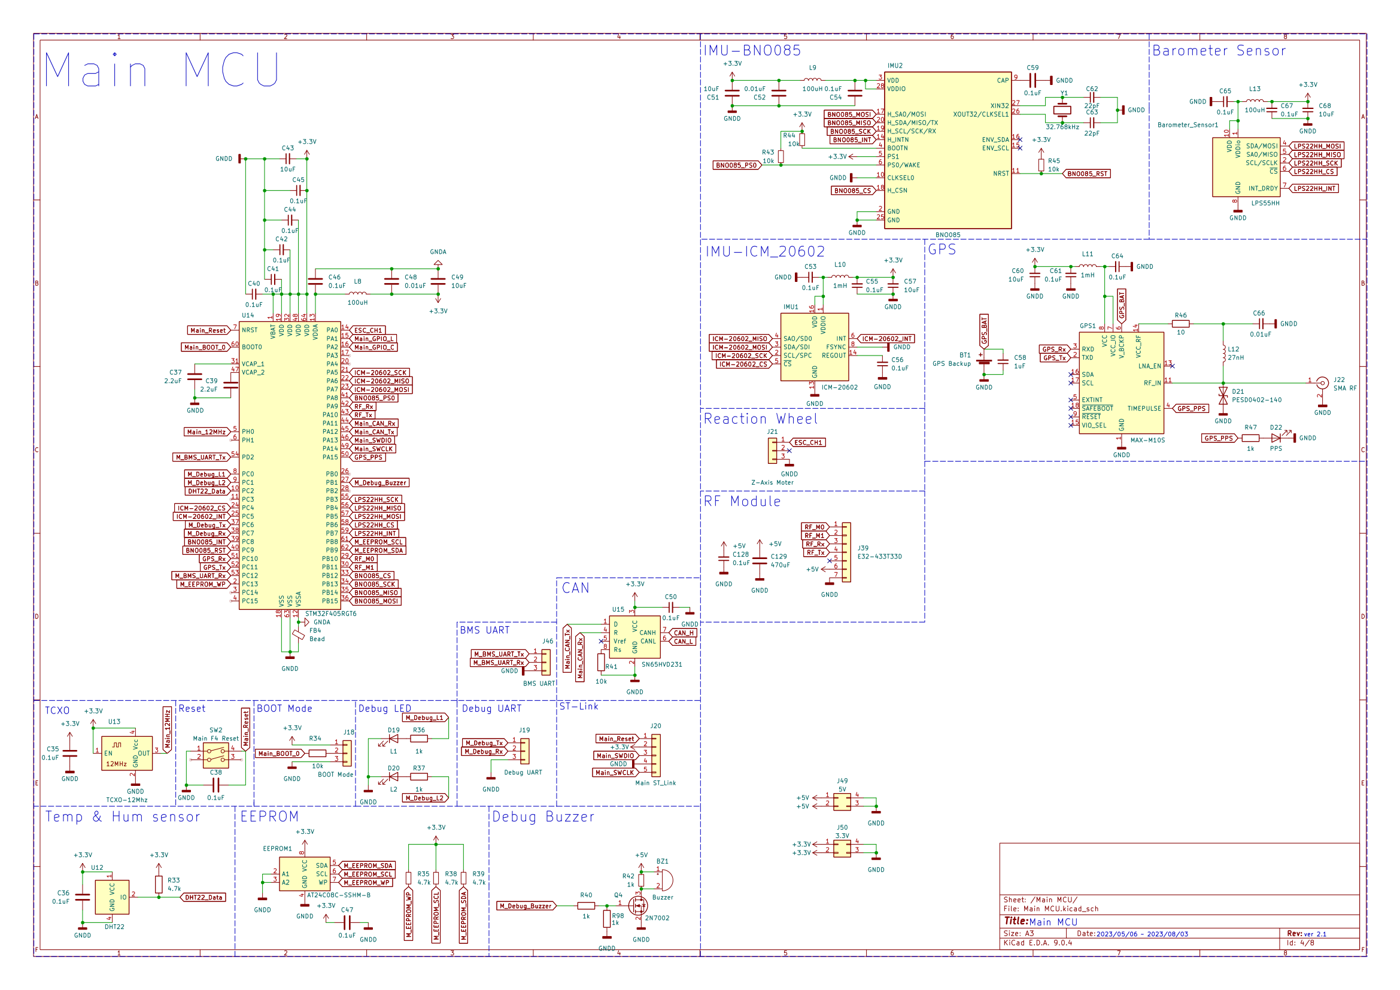
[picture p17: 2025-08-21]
docs/images/main-mcu.png

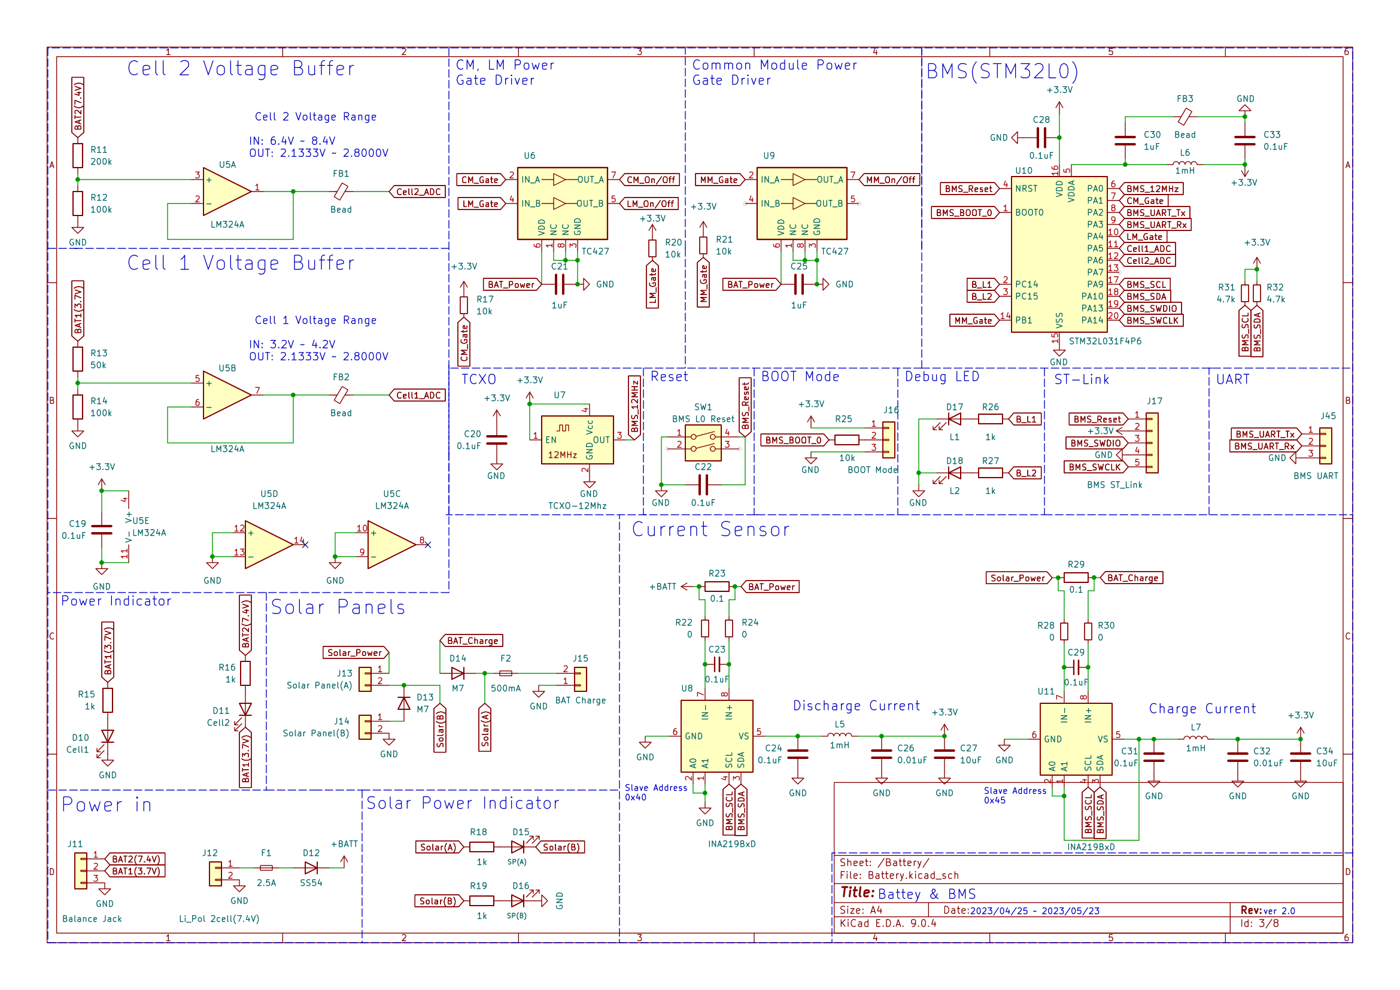
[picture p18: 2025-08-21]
docs/images/battery-bms.png

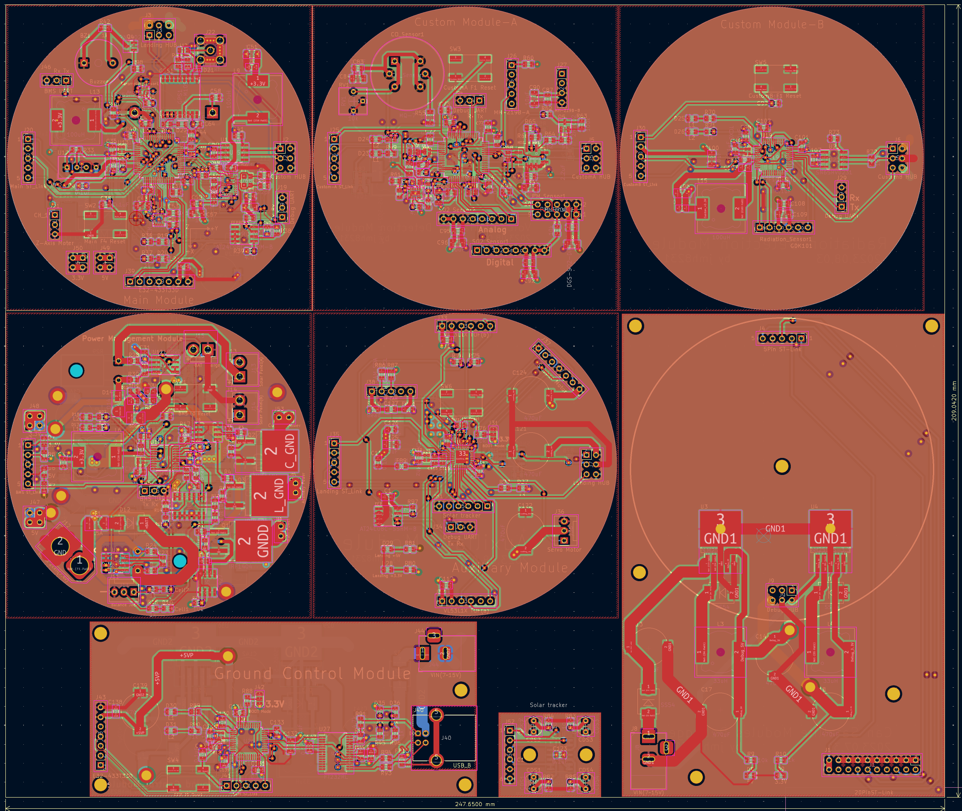
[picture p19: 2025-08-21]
docs/images/pcb-layout.png

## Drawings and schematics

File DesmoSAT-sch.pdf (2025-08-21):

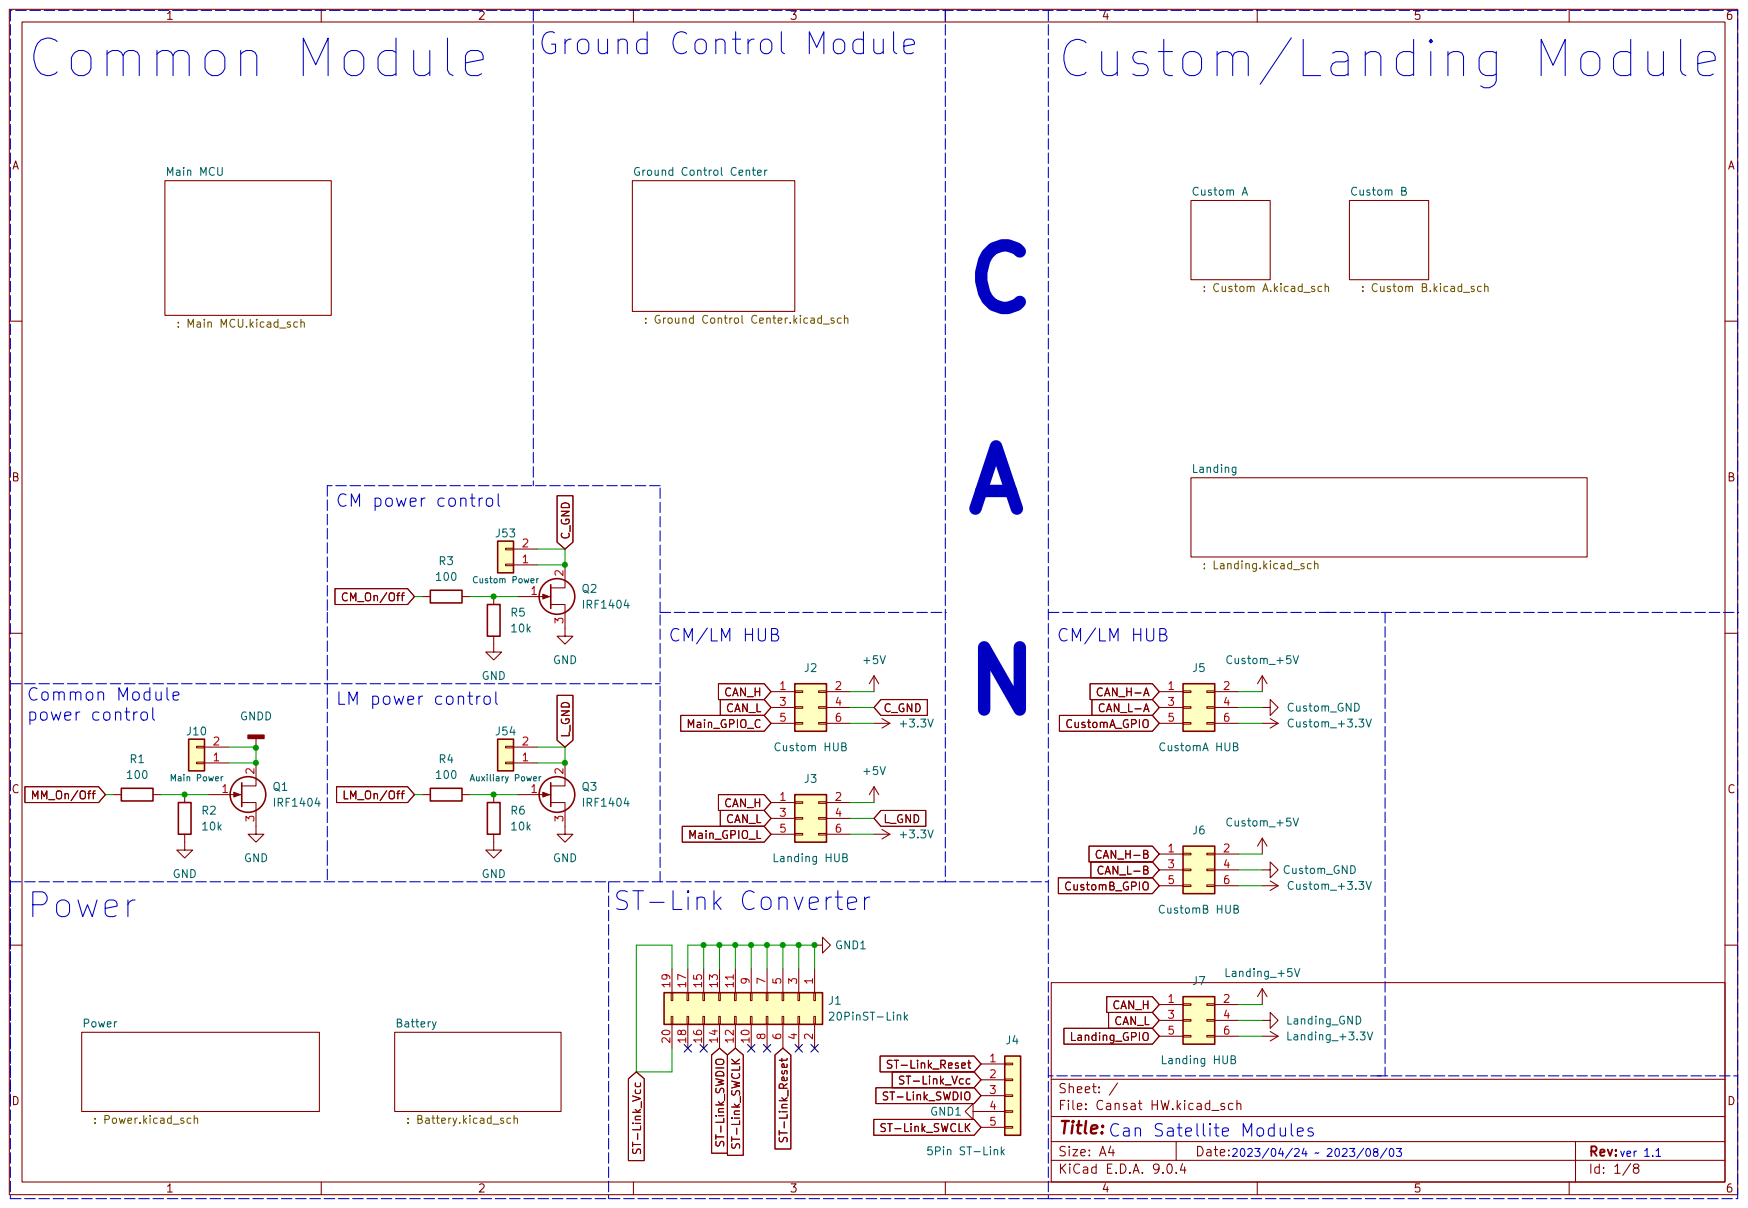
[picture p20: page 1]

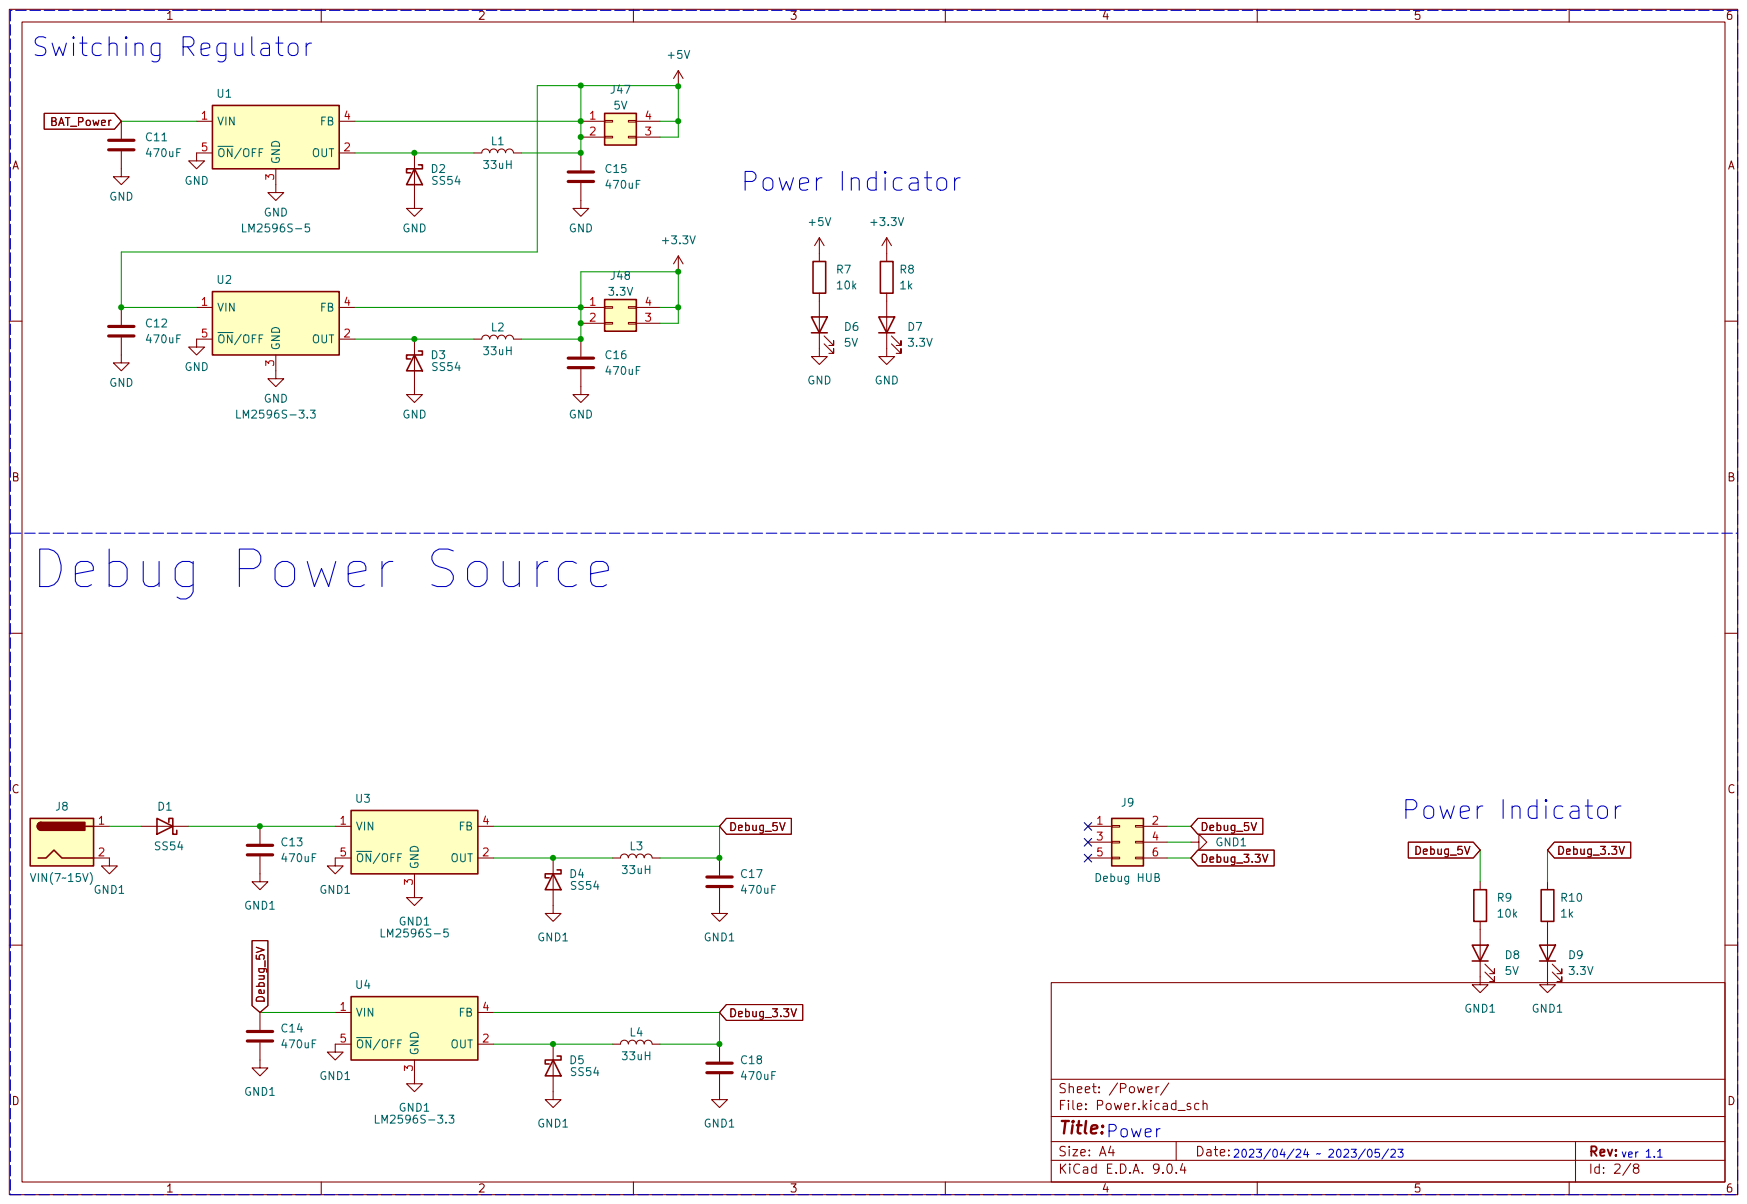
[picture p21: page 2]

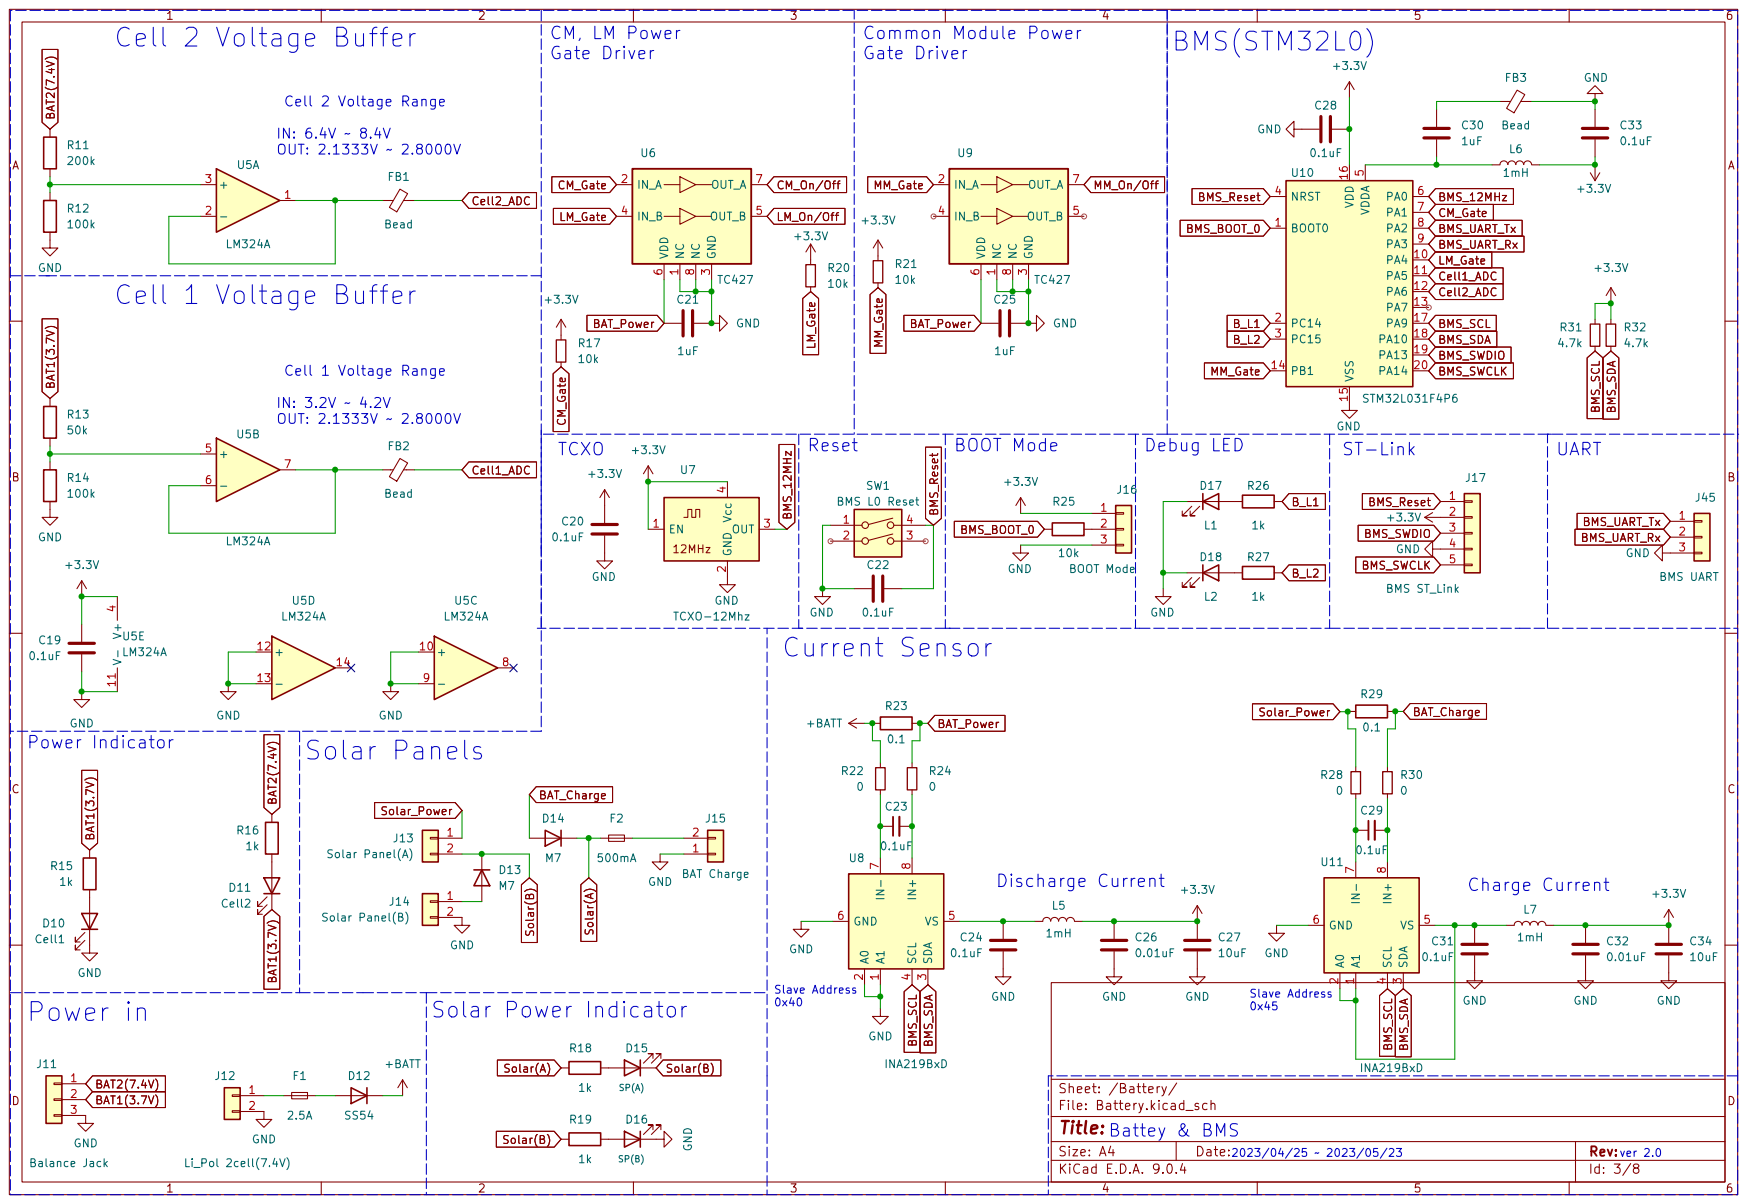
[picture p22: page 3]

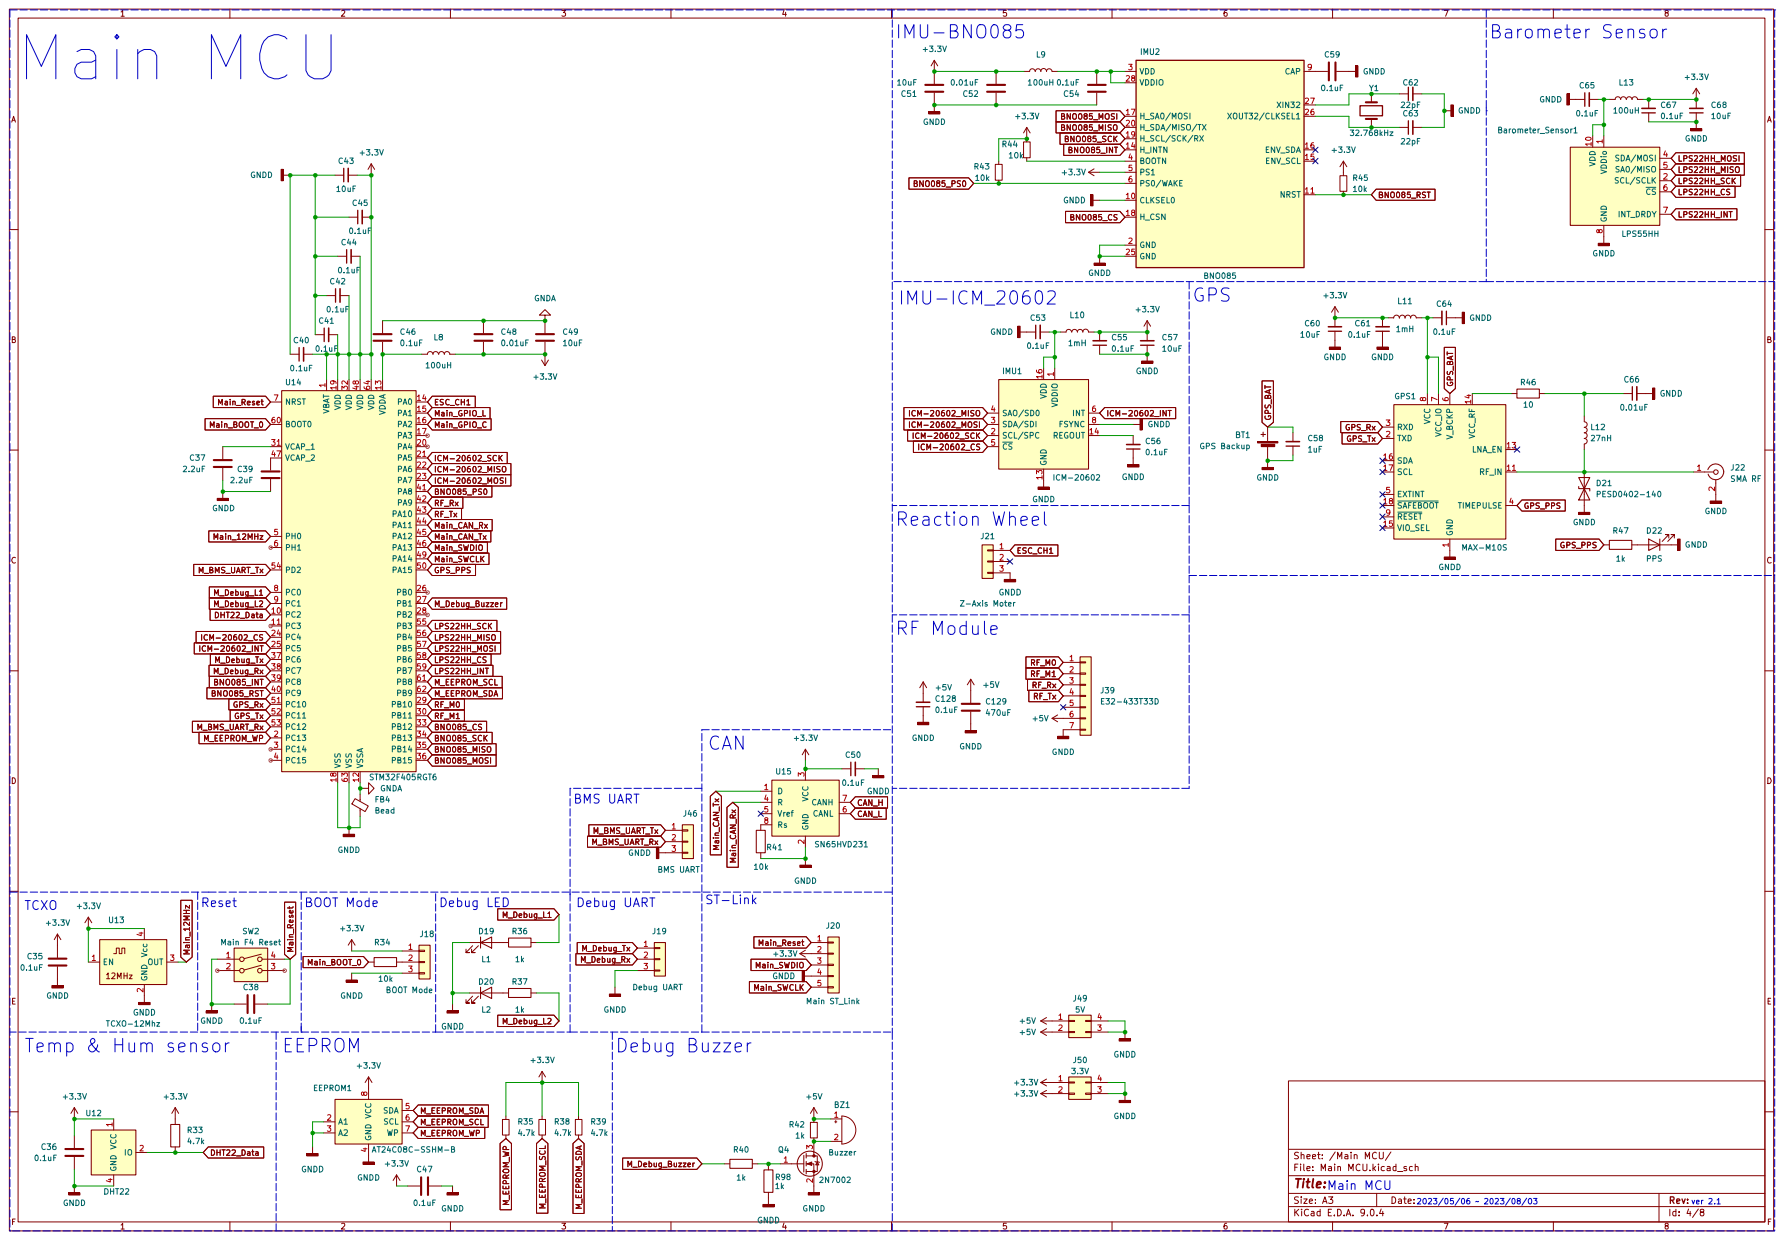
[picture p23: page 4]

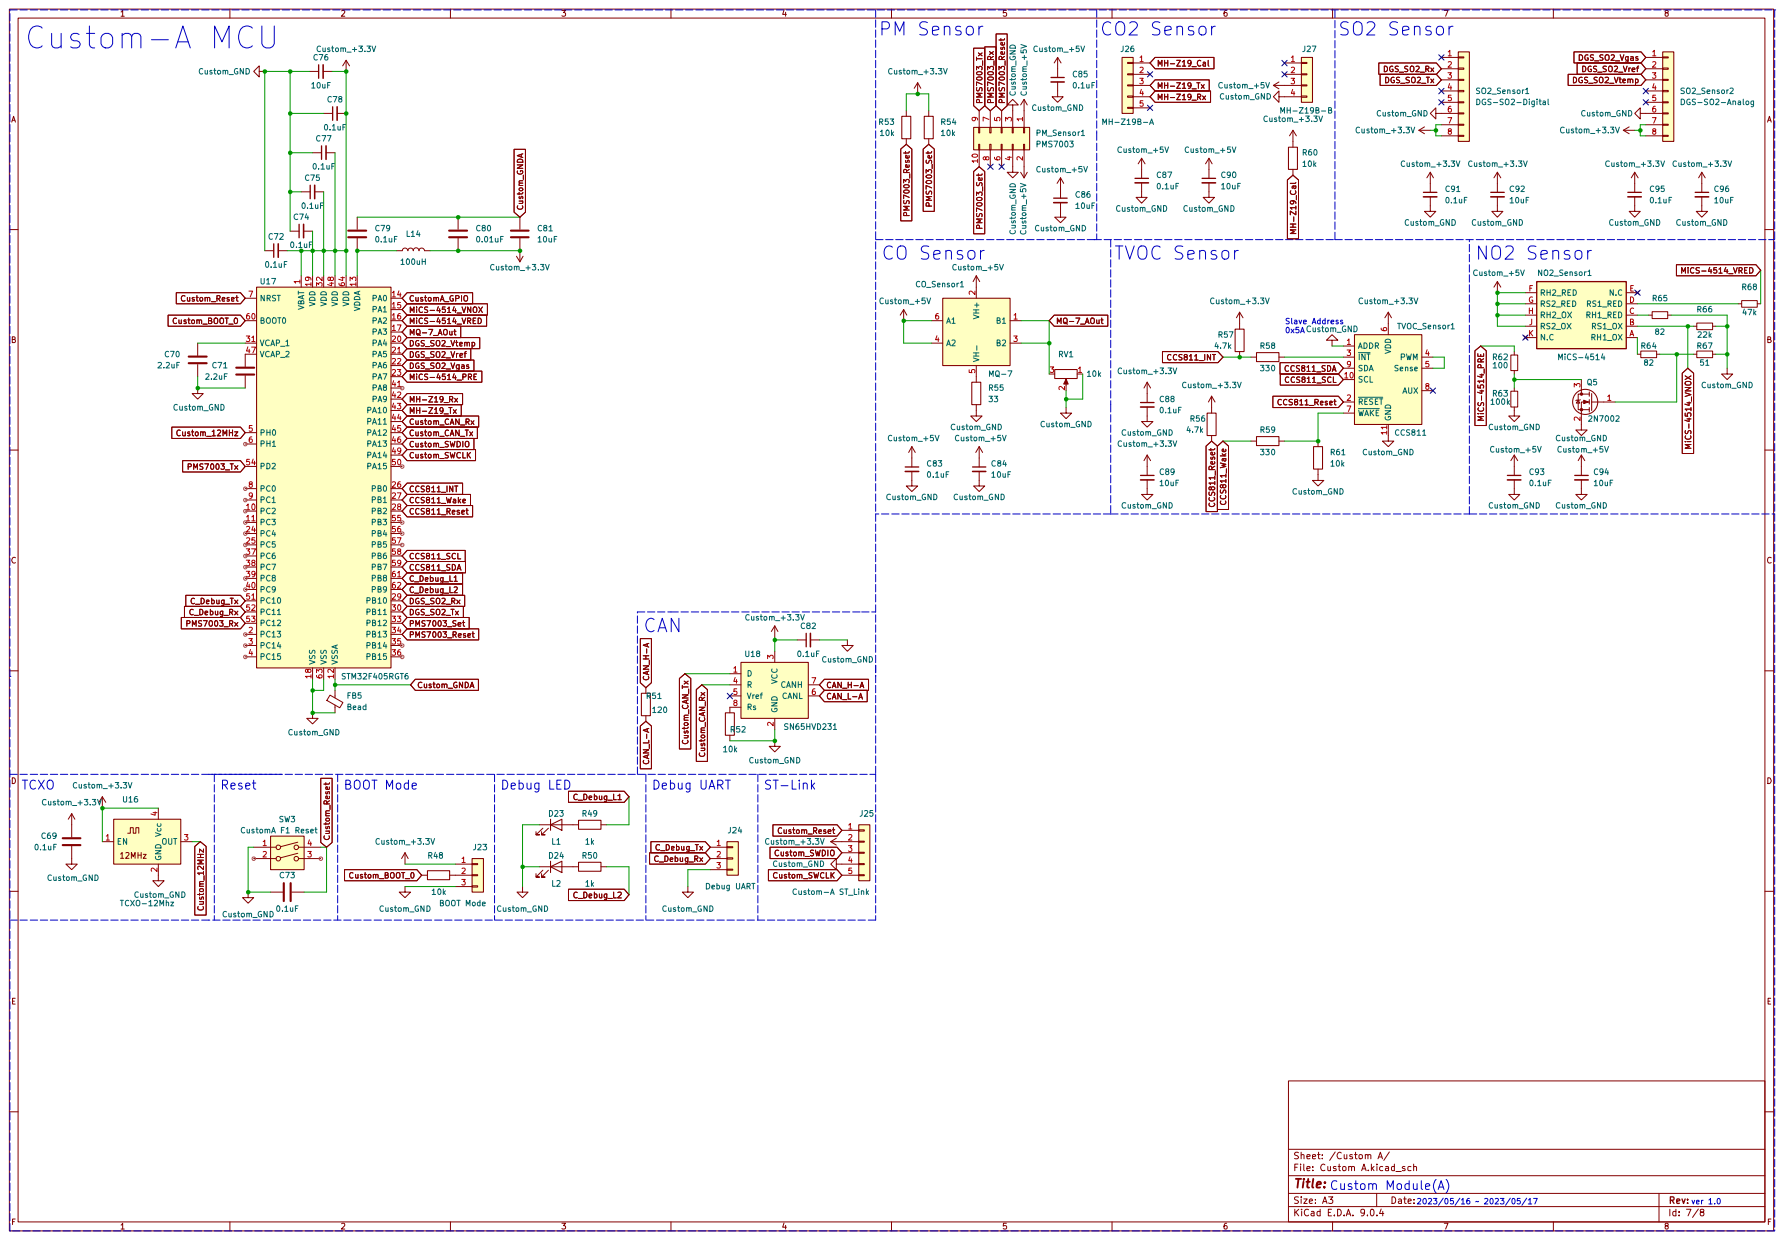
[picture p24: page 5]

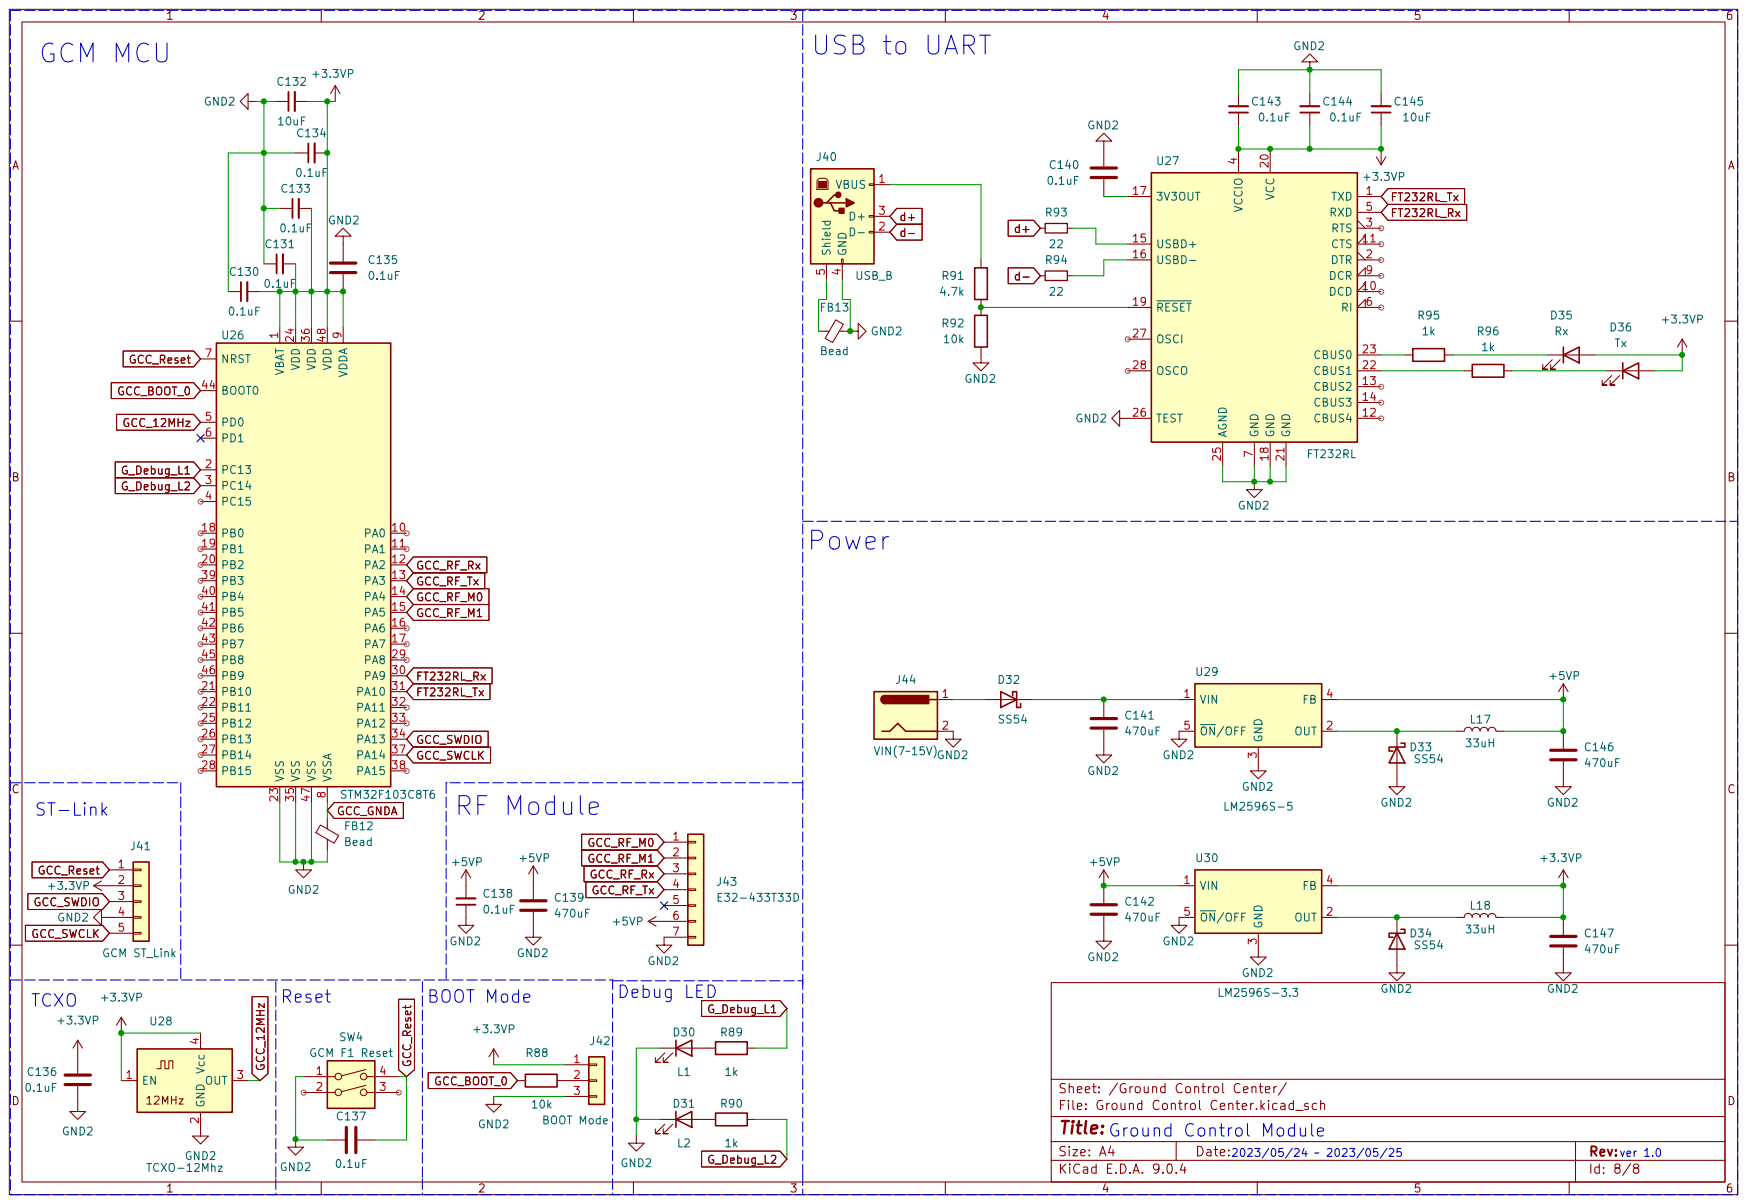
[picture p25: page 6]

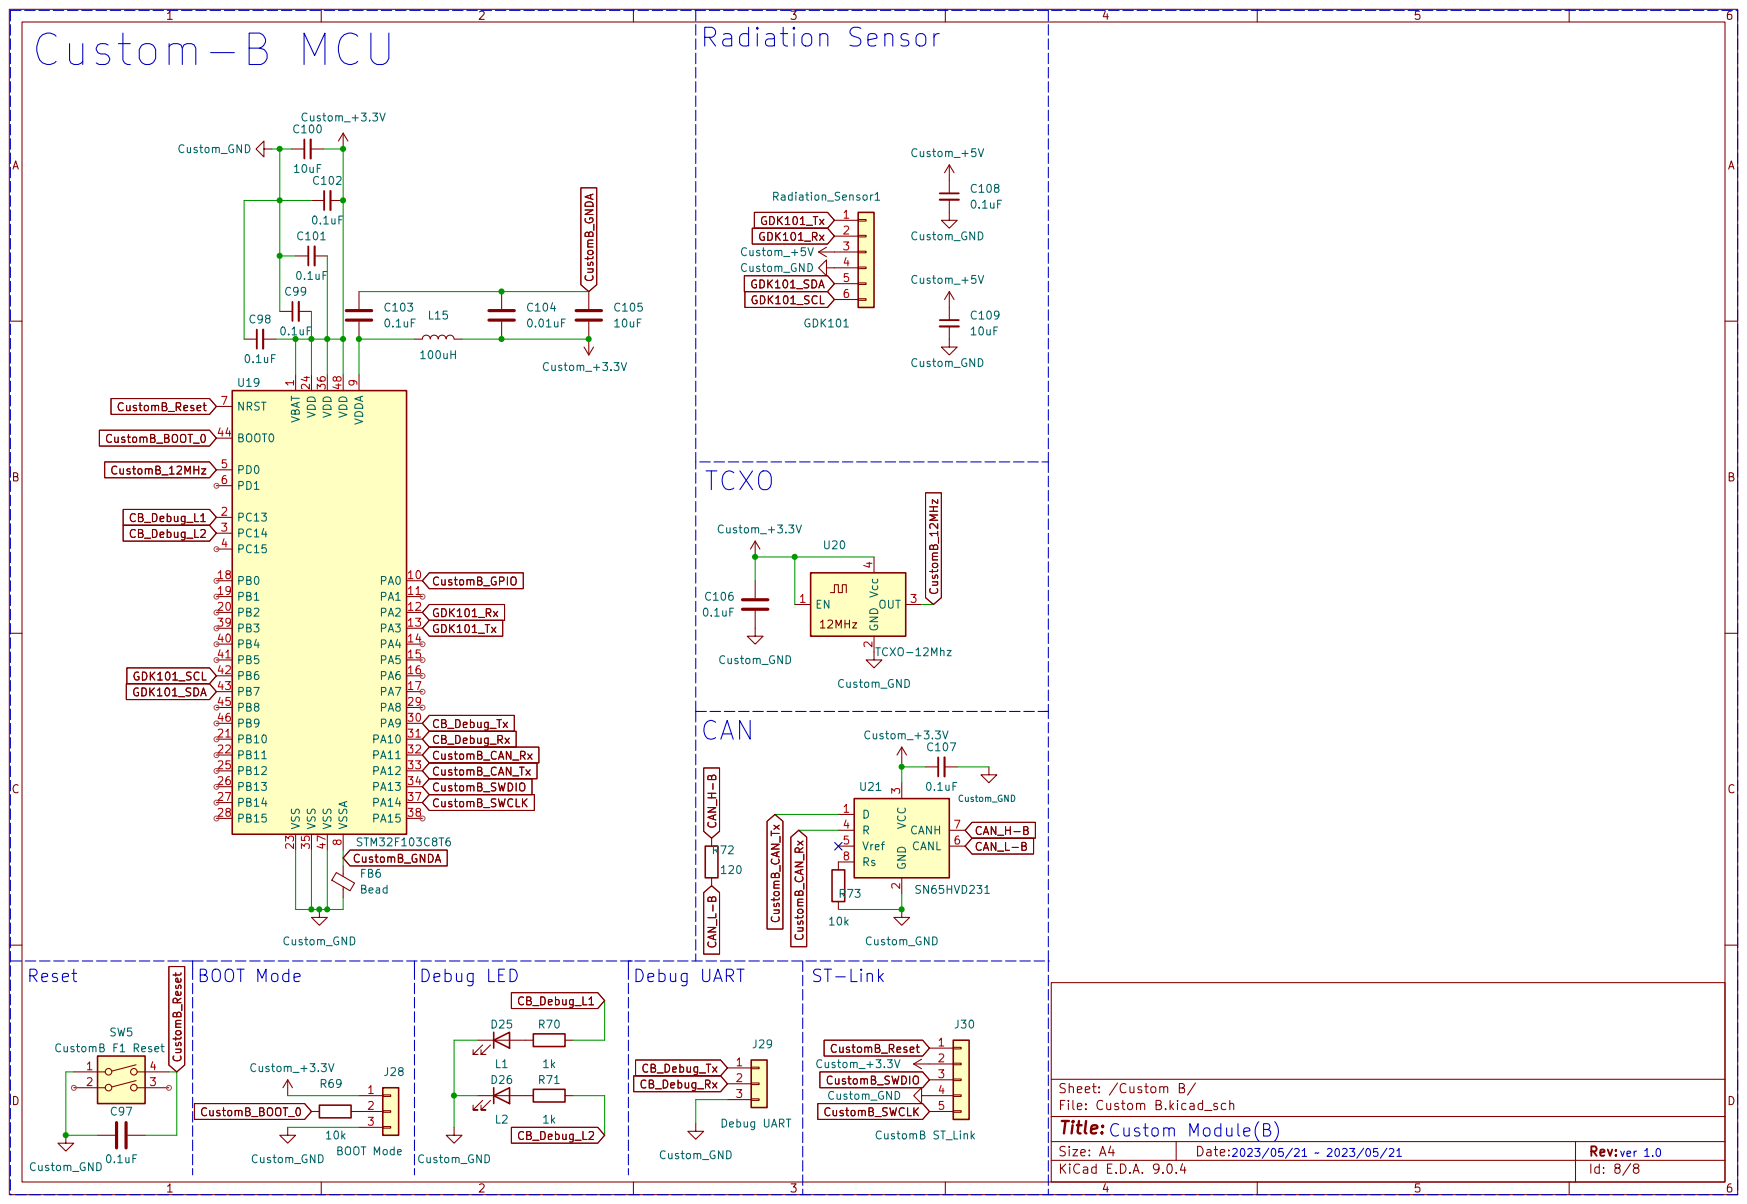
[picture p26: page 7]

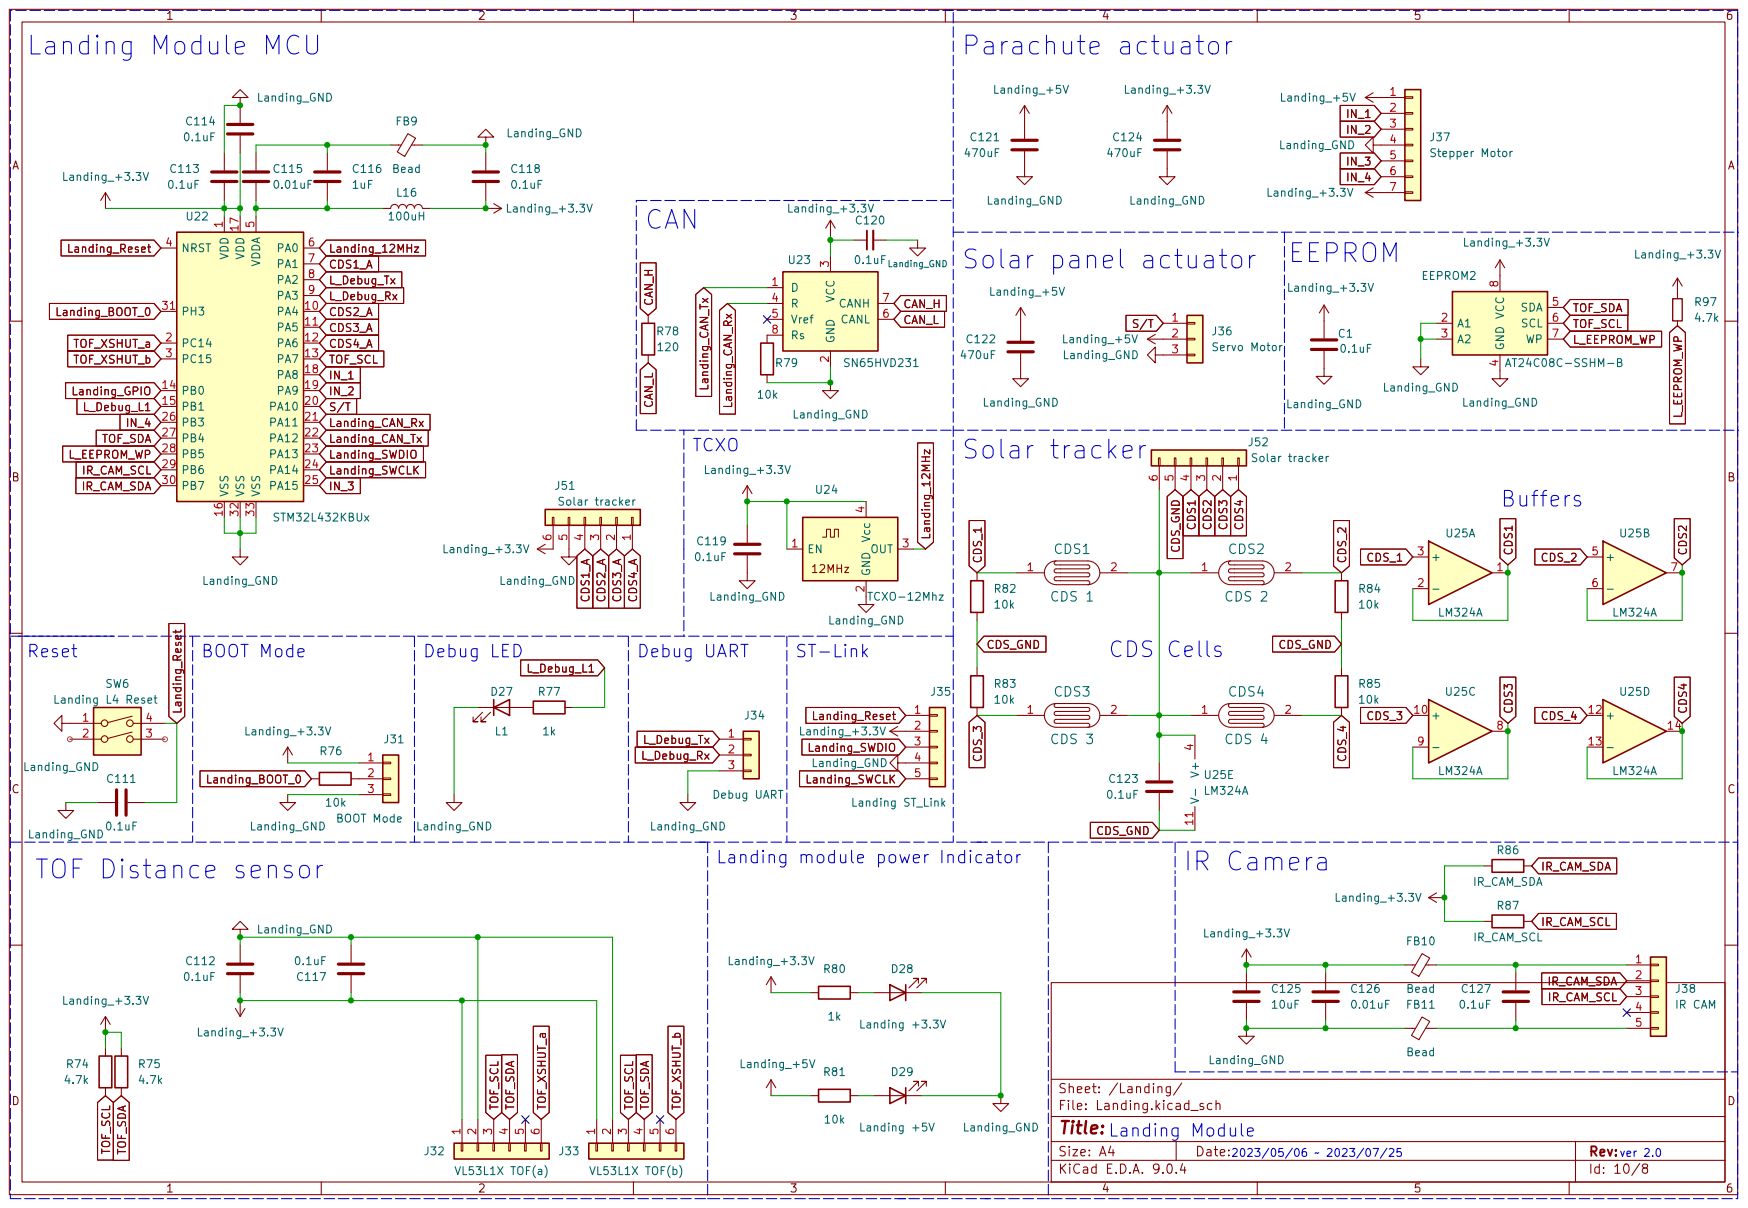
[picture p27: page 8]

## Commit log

2025-08-20 DesmoSAT v1.0
    [Battery.kicad_sch, Cansat HW.kicad_sch, Custom A.kicad_sch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]
2025-08-21 회로 이미지 추가
2025-08-21 임무제안서 추가
2025-08-21 회로도(PDF) 추가
2025-08-21 PCB 이미지 추가
